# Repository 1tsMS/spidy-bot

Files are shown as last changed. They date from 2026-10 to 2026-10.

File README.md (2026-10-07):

# Spidy Bot

A 3D-printed 12-servo quadruped (ESP32 + PCA9685 + MG90S), with a MuJoCo model, leg IK, a crawl gait in simulation, and a desktop control app.

**Status:** stands and does slow sit/stand with some help. The crawl and turning work in simulation only. The real robot doesn't walk: the front legs don't have enough servo torque (details below).

## Hardware

| Part | Used |
|---|---|
| Frame | PLA, designed in Fusion 360, 4 legs × 3 joints (hip, knee, claw) |
| Servos | 12× MG90S |
| Servo driver | PCA9685 @ 0x40, 50 Hz, with a custom breakout board on top |
| Controller | ESP32 (uPesy Wroom DevKit), Wi-Fi |
| IMU | MPU6050 |
| Battery | 3S 11.1 V 2200 mAh LiPo |
| Servo supply | 12 A 300 W buck, set to 6 V |
| ESP supply | Mini360 buck, 5 V, fed from the battery side |

Leg lengths: coxa 34.2 mm, femur 55.8 mm, tibia 88.9 mm. Total mass 704 g.

## Software

| Path | What |
|---|---|
| `Codess/Software/` | **Old version.** ESP32 firmware with calibration hardcoded on the board, plus a PyQt5 tool for per-servo calibration and poses. |
| `Codess/Software2.0/` | **New version.** PySide6 app: live MuJoCo view, joystick driving, calibration wizard, pose library, 50 Hz Wi-Fi streaming to the robot. Run `Spidy.bat` or `python run_app.py`. |
| `firmware/spidy_fw/` | Firmware for the new app. All calibration lives on the PC; the ESP only drives pulses, holds the last pose if Wi-Fi drops, and reports its reset reason and I2C health. |
| `Codess/Simulation/sim_walk/` | Walking in MuJoCo step by step: IK, standing, body shift, crawl, turning. |
| `URDF/spidy_description/` | URDF and MuJoCo model generated from the Fusion CAD. |

Wi-Fi credentials go in `secrets.h` (copy `secrets.example.h`); it's gitignored.

## Problems and what fixed them

1. **Servo horns at the wrong angle.** Each servo was centred to 90° in software *before* its horn was screwed on, so all legs started from a known position.
2. **"90°" didn't look like 90° on the real legs.** Horn splines and print tolerances left every joint a few degrees off. Added a per-servo offset and direction, saved to a calibration file.
3. **Couldn't sit and stand.** A direct move overloaded the knees. I found a working standing pose (`Standf`, knees bent, tibias vertical) and an ordered chain of intermediate poses by hand. The new app adds IK-planned sit/stand sequences and a step reducer (aggressive / balanced / conservative).
4. **Power.** The original 18650 cells + XL4015 buck sagged under servo load. Replaced them with a 3S 2200 mAh LiPo and a 12 A buck.
5. **Thin PCA9685 power traces.** The board's own traces can't carry 12 servos' current. Made a breakout board that sits on the PCA9685 like a hat, with header pins and thick solder traces for servo power.
6. **ESP32 rebooting during moves.** Brownouts from servo current spikes. Confirmed by having the firmware report the ESP32's reset reason (`boot=BROWNOUT`). Fixed by:
   - moving the Mini360 input from the 6 V servo rail to the battery side,
   - adding 1000 µF + 100 nF at the ESP,
   - adding 1000 µF on the servo rail at the breakout.
7. **Servo scale was wrong.** The old firmware's "degrees" were ~1.46 real degrees (pulse range 100–700 ticks vs the MG90S's 0.5–2.5 ms). Found it because the real Sit pose only matched the sim at that scale. Corrected in the calibration, with pulses unchanged.

## Open problem: weak front legs

This has been there since day one, and the power and wiring fixes didn't change it.

- **Cause:** the battery and buck sit at the front, so the centre of mass is ~12 mm forward.
- In simulation the front knees need **~43% of a genuine MG90S's stall torque just to stand**, against ~29% for the rear knees.
- Servos can only hold roughly 25–50% of stall continuously, and most MG90S sold are clones with well under the rated 2.2 kg·cm. So the front knees run at or past their limit, and transitions need help.
- Swapping the front servos didn't fix it.
- **Likely fixes:** move the battery ~30 mm back (balances front and rear in sim), and use stronger knee servos (≈3.5 kg·cm, e.g. MG92B).

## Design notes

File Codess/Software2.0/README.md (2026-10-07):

# Spidy Control app

Desktop app to calibrate, pose and walk Spidy, in the MuJoCo sim and on the real robot.

```
pip install -r requirements.txt
python -m app                 # from Codess/Software2.0
python -m unittest discover -s tests -v      # from Codess/Software2.0
```

## Layout

| Path | What |
|---|---|
| `spidy/` | Core, no GUI: kinematics, gait, calibration, link, sim, IMU, poses |
| `app/` | PySide6 GUI: Dashboard, Motors, Calibration wizard, Poses |
| `config/calibration.json` | The ONLY calibration. Imported once from `../Software/spidy_calibration3.txt` |
| `config/poses.json` | Poses in joint degrees + sequences. Imported once from `spidy_poses.txt` |
| `firmware/spidy_fw/` | New firmware: pulses in, servos out. Needs `secrets.h` (copy `secrets.example.h`) |

## Calibration model

```
ticks = center + direction * ticks_per_deg * joint_deg      (clamped to min/max joint degrees)
```

`joint_deg` is the same angle the sim and IK use (0 = femur flat, tibia vertical).

## Safety

- Nothing reaches the real servos unless the target is REAL/BOTH **and** ARM is on.
- Arming first reads the servos' current pulses (`STATE`) so streaming starts there, without a jump.
- Every target goes through a 240°/s slew limit and each joint's min/max.
- E-STOP (button or Space) turns every output off and disarms.
- If the stream stops for 300 ms, the firmware holds the last pose.

## Keys

W/S forward/back, A/D turn (combine for arcs), Space = E-STOP. Gamepad: left stick, A stand, B sit, Back = E-STOP.

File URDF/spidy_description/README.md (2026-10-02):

# spidy_description

URDF + MuJoCo model of Spidy, generated from the Fusion model `MS makda urdf 2`.

## Layout

| Path | What | Edit by hand? |
|---|---|---|
| `urdf/spidy.urdf.xacro` | Robot structure: links, joints, leg macro | **Yes**, this is the URDF to read and learn from |
| `urdf/spidy_generated.xacro` | Numbers: lengths, masses, inertias | No, it's written by `build_description.py` |
| `urdf/spidy.urdf` | Plain expanded URDF (meshes `../meshes`) | No, regenerate with xacro |
| `config/masses.yaml` | Mass budget (**estimates**, weigh and replace) | Yes |
| `config/fusion_transforms.json` | Component placements exported from Fusion | No |
| `meshes/*.stl` | One mesh per link, in that link's frame, metres | No |
| `mujoco/spidy.xml` | MuJoCo model: free base, floor, 12 position servos, IMU | No, it's written by `urdf_to_mujoco.py` |

## Use

```bash
pip install -r requirements.txt
python -m mujoco.viewer --mjcf=mujoco/spidy.xml      # open it, drag the ctrl sliders
python scripts/check_model.py                        # joint-axis images + stand torque audit
```

After weighing parts (edit `config/masses.yaml`):

```bash
python scripts/build_description.py --raw ../raw_world_stl   # meshes + spidy_generated.xacro
xacro urdf/spidy.urdf.xacro mesh_prefix:=../meshes > urdf/spidy.urdf
python scripts/urdf_to_mujoco.py
```

## Conventions

- Frame: x forward, y left, z up. Base origin is the body centre at knee-axis height.
- Zero pose: the pose in the Fusion model (femur horizontal, tibia vertical).
- Every leg uses the same axes: hip +z, knee +x, claw +x. So `+knee` lifts a left leg and lowers a right leg. The gait code handles the mirroring.
- Joint limits are ±90° placeholders until they're mapped from the servo calibration.

## Leg geometry (from Fusion)

| | mm |
|---|---|
| hip axes from body centre | x ±60, y ±50 |
| coxa (hip → knee) | 34.2 |
| femur (knee → claw) | 55.8 |
| tibia (claw → foot tip) | 88.9 down; tip sits 5.0 toward body centre (x) and 1.2 inward (y) |

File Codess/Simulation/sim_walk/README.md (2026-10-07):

# sim_walk: making Spidy walk in MuJoCo, one idea per file

Each step builds on the one before and runs on its own. Run them from `Codess/Simulation`.

| File | Idea | Run |
|---|---|---|
| `step1_leg_ik.py` | FK + IK for one leg, tested against MuJoCo. Converts your logical servo degrees (Standf) to joint angles | `python sim_walk/step1_leg_ik.py` |
| `step2_stand.py` | Stand in Standf, feet planted, move the body (height, sway, twist) | `python sim_walk/step2_stand.py` |
| `step3_body_shift.py` | Shift the COM over 3 feet before lifting the 4th | `python sim_walk/step3_body_shift.py` (try `--no-shift`) |
| `step4_crawl.py` | Wave gait: body moves continuously, one leg swings at a time, body sways | `python sim_walk/step4_crawl.py` |
| `step5_turn.py` | Turning: stance feet sweep arcs instead of straight lines | `python sim_walk/step5_turn.py` |

Add `--headless` to any of them to skip the viewer and print a test report instead.

`simrun.py` is shared plumbing (load the model, real-time loop, measurements). No walking ideas live here.

## Assumptions to check on the real bot

- `STANDF = [90, 105, 75]` from `Codess/Software/spidy_poses.txt`, read as knee +15 / claw -15 from the modelled pose.
- +knee raises the femur on every leg (implied by the Sit pose). Hip direction is not verified.
- `DEG_PER_LOGICAL = 1.0`: one logical degree is assumed to be one real degree. Not measured.

## Results (704 g model, servo stall 0.21 N*m)

- Crawl: 2.9 cm/s, 14 mm stability margin, about 1 deg body tilt.
- Servo load while crawling straight: knee ~87%, claw ~74% of stall.
- Turning: arc +47 deg (asked ~50), spin -65 deg (asked ~62). Knees reach ~92% while spinning: the tightest case.

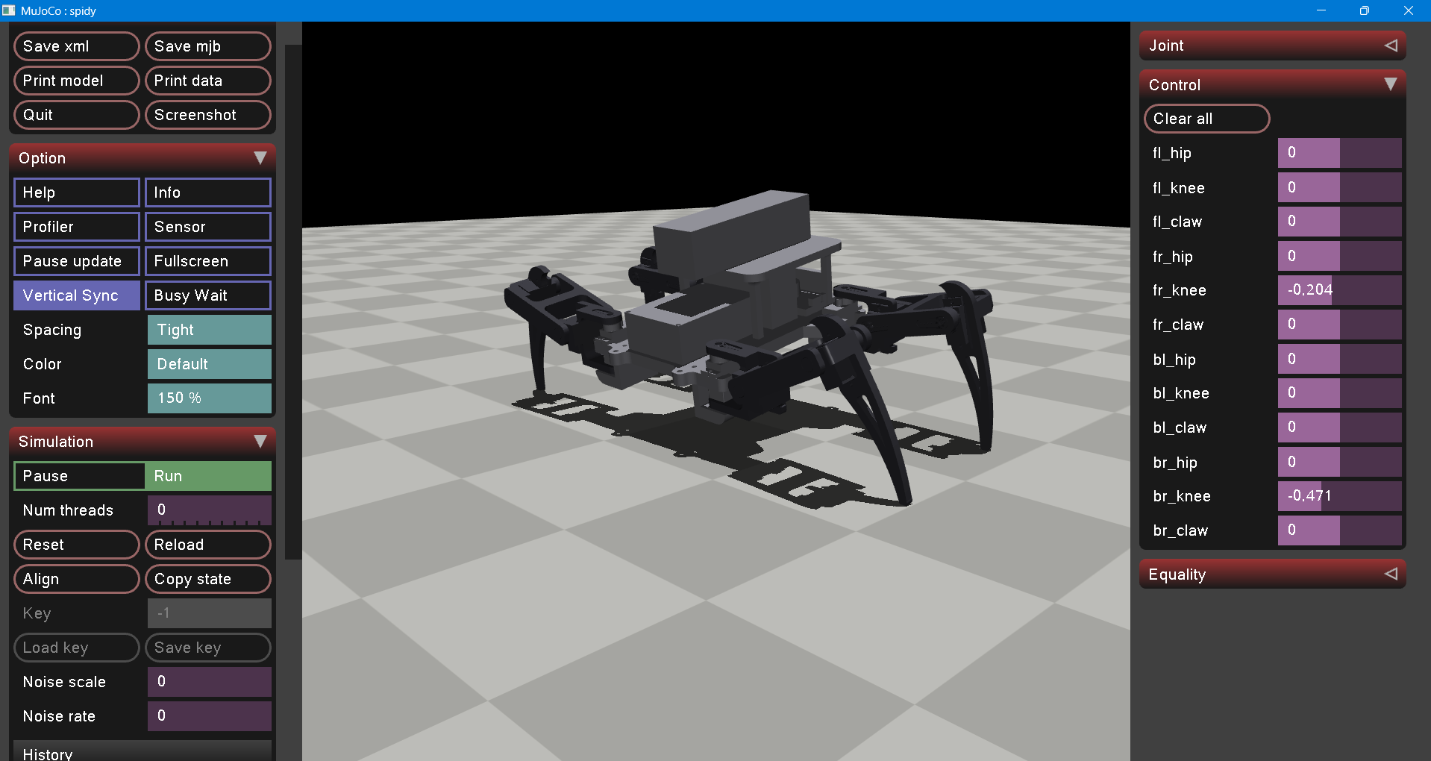
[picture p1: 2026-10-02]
images/Screenshot 2026-10-02 173417.png

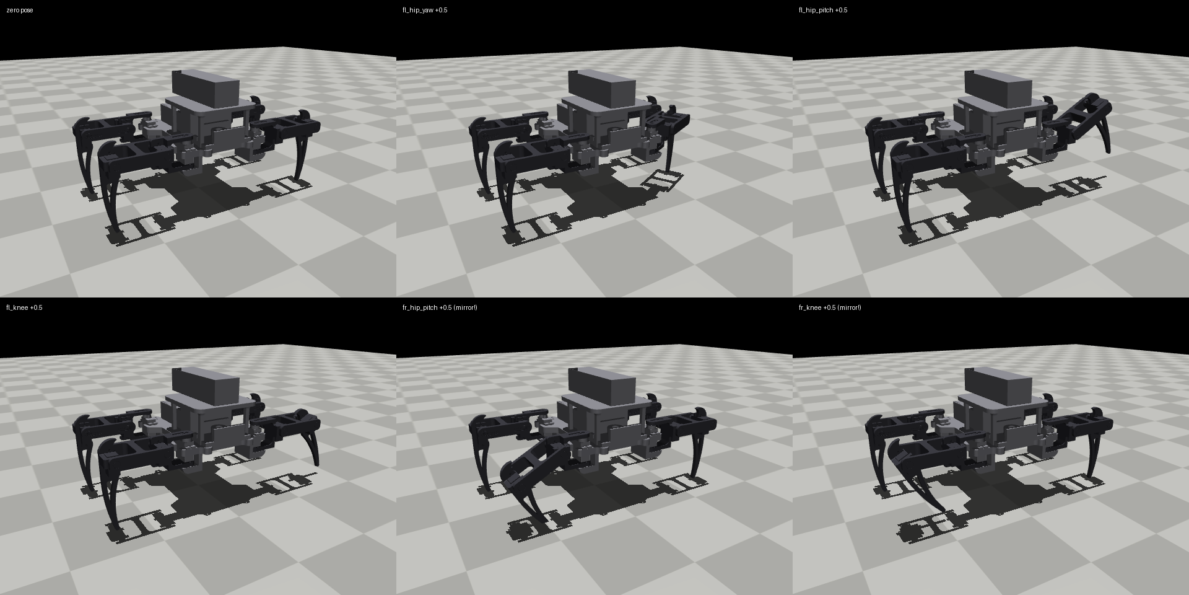
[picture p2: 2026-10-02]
images/joint_axes.png

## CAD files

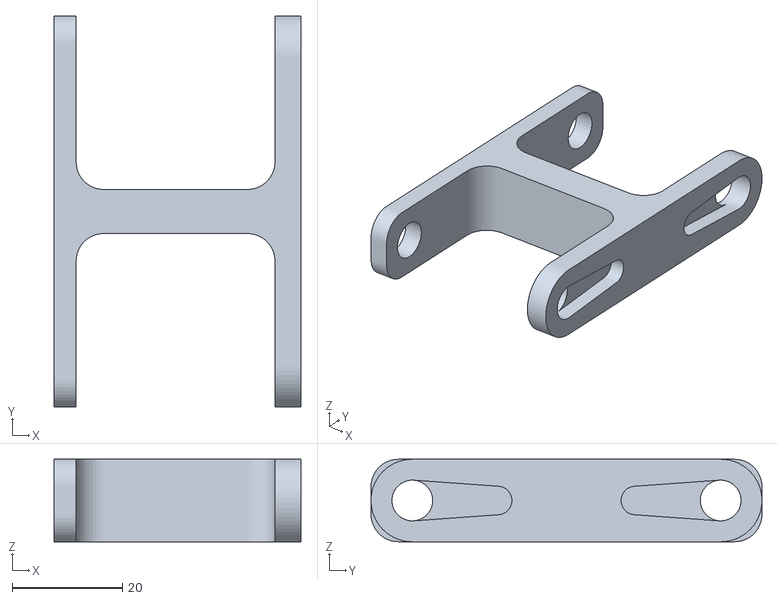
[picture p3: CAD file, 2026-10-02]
Final Parts/Link.stl
44.8 x 71.0 x 15.0

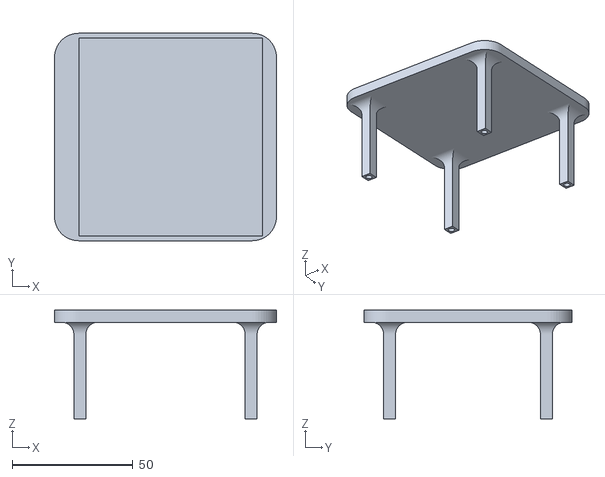
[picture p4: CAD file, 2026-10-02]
Models/Table.stl
92.0 x 86.0 x 45.0

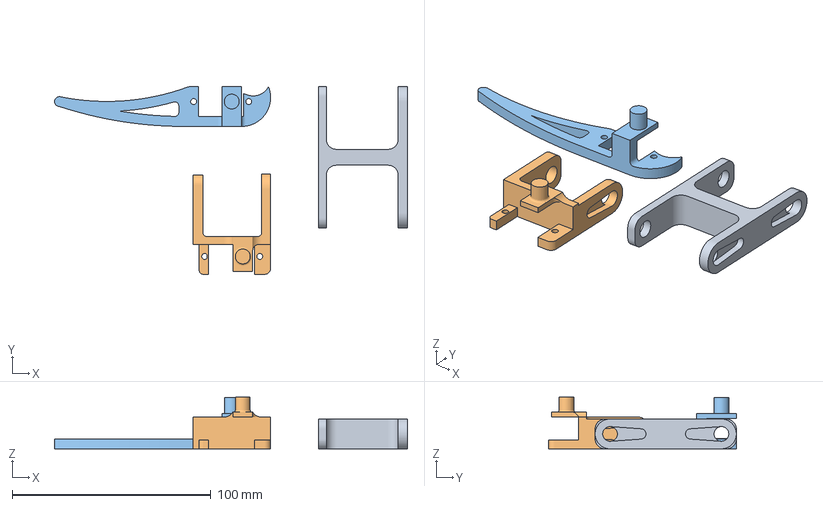
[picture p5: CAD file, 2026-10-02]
Prints/leg.3mf
177.4 x 94.4 x 26.0 mm
Part 2.stl
part1.stl
Body1.stl

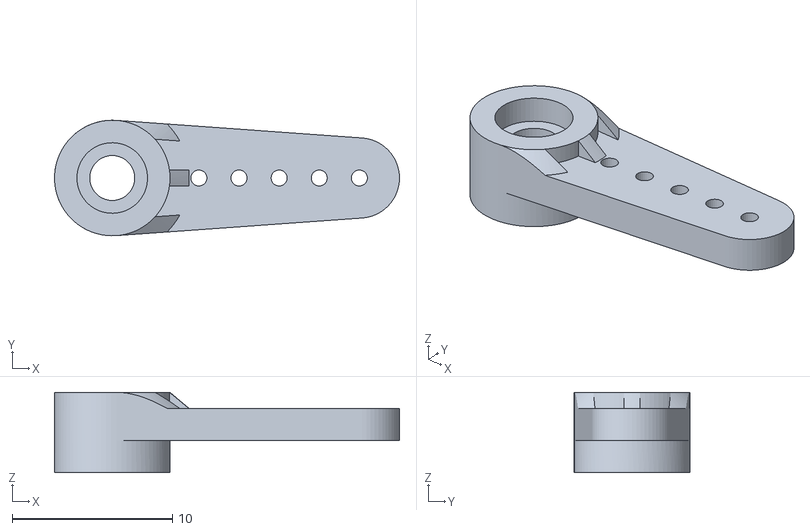
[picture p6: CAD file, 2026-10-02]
URDF/raw_world_stl/m2_horn_fl.stl
21.5 x 7.20 x 5.00

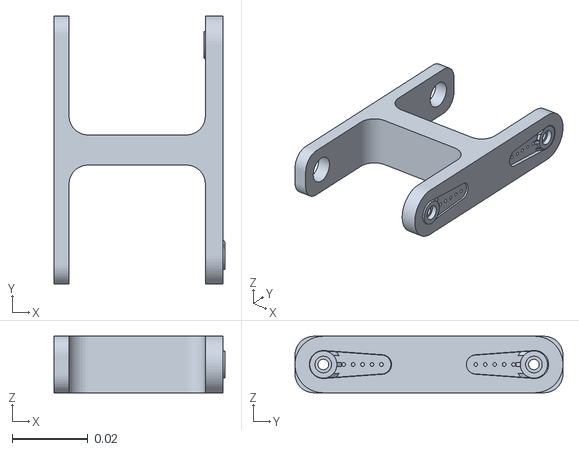
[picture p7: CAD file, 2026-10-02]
URDF/spidy_description/meshes/br_femur.stl
0.0453 x 0.071 x 0.015

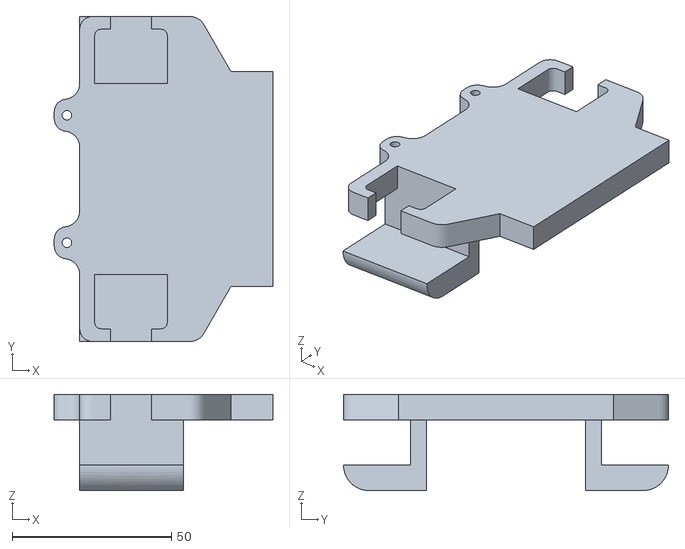
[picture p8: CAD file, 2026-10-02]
Final Parts/body test.stl
68.6 x 102.0 x 30.2

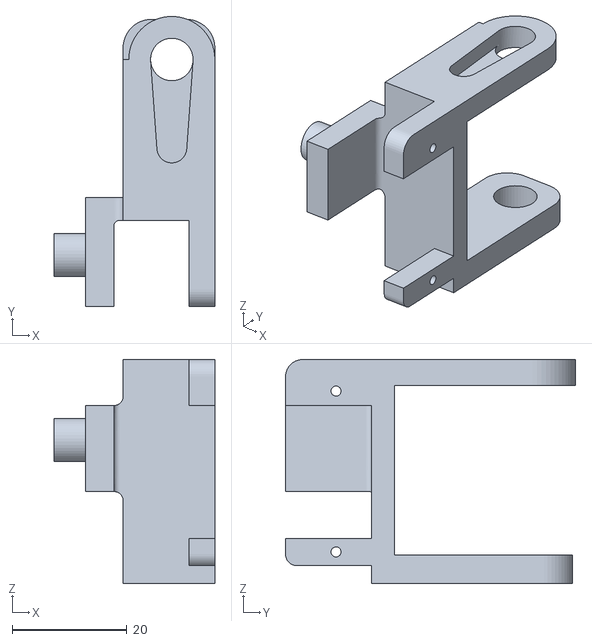
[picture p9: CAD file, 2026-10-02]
Models/Body3.stl
28.0 x 50.5 x 39.0

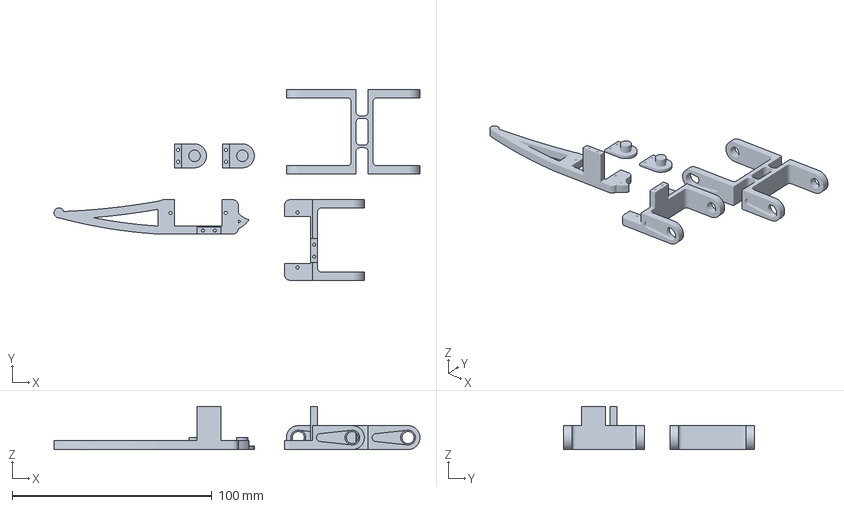
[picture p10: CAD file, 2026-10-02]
Prints/leg r.3mf
183.4 x 95.6 x 21.6 mm

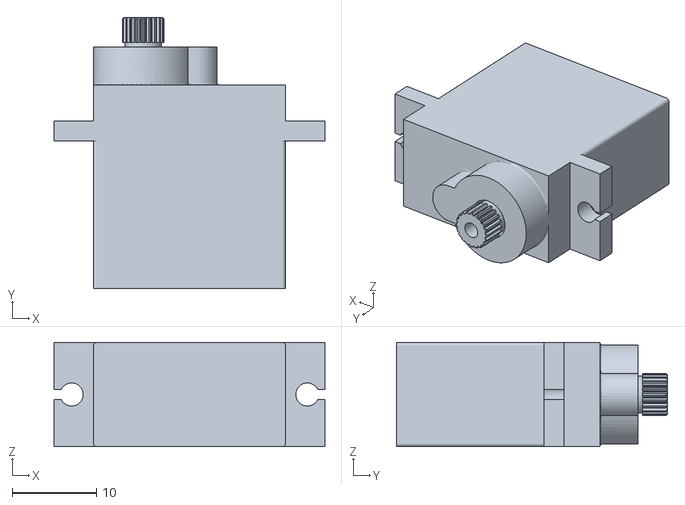
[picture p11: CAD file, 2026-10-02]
URDF/raw_world_stl/m1_fl.stl
32.2 x 32.2 x 12.4

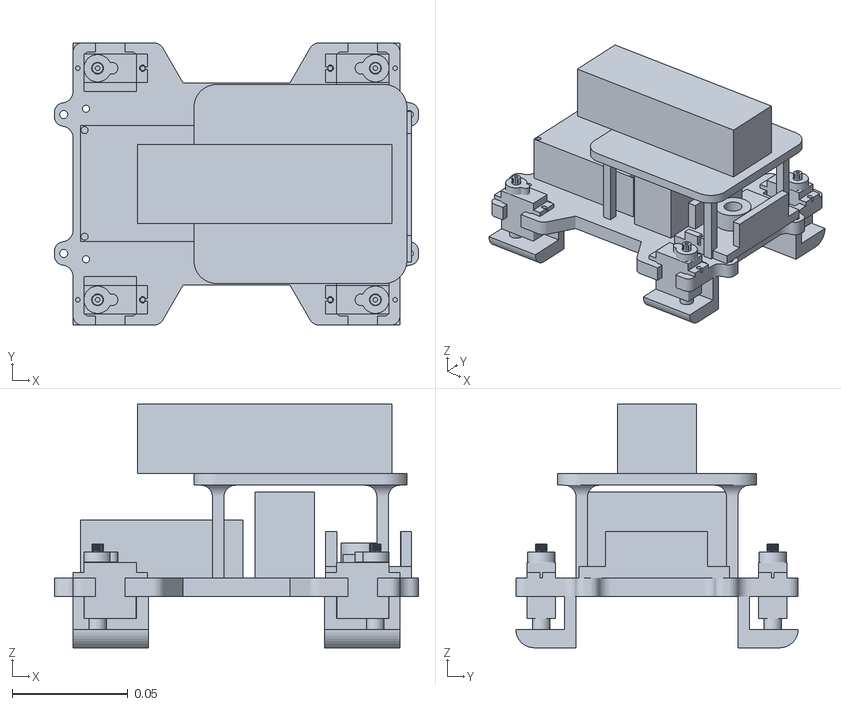
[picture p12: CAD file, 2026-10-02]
URDF/spidy_description/meshes/base_link.stl
0.157 x 0.122 x 0.105

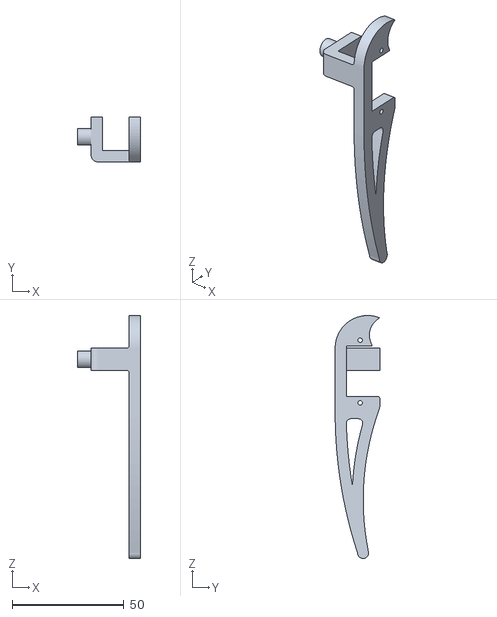
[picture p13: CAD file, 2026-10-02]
Final Parts/Leg1_claw.stl
28.0 x 20.0 x 108.6

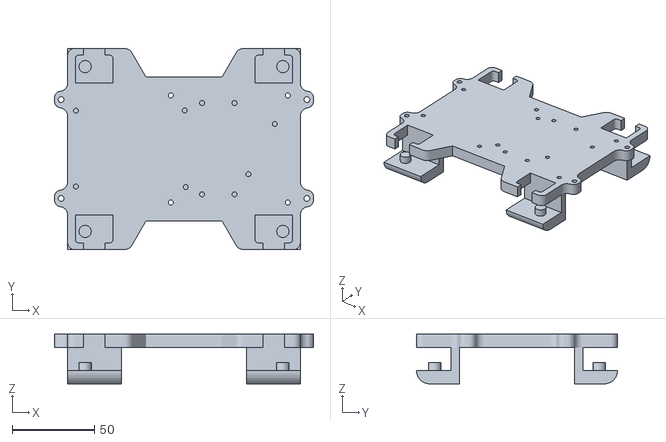
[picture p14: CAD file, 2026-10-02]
Models/Chassis.stl
157.2 x 122.0 x 30.2

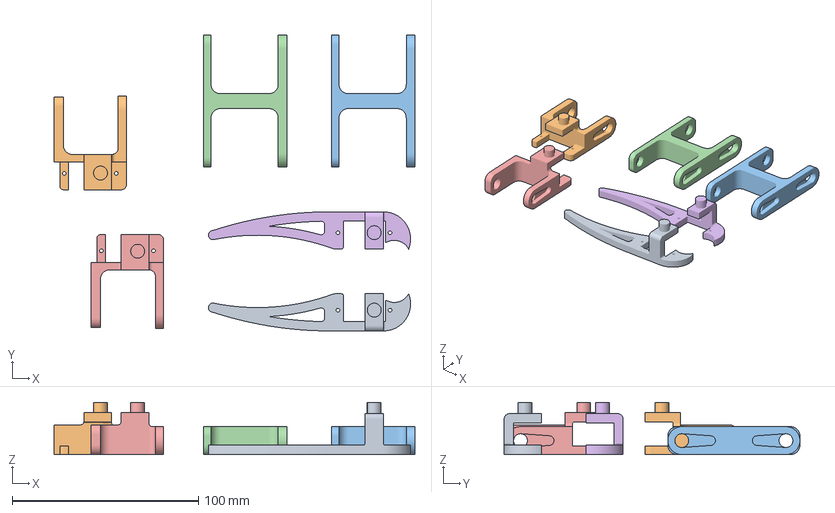
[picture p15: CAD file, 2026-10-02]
Prints/2legs.3mf
194.0 x 159.0 x 28.0 mm
Leg1_claw.stl
Leg1_Shldr.stl
Link.stl x 2
Leg2_Shldr.stl
Leg2_Claw.stl

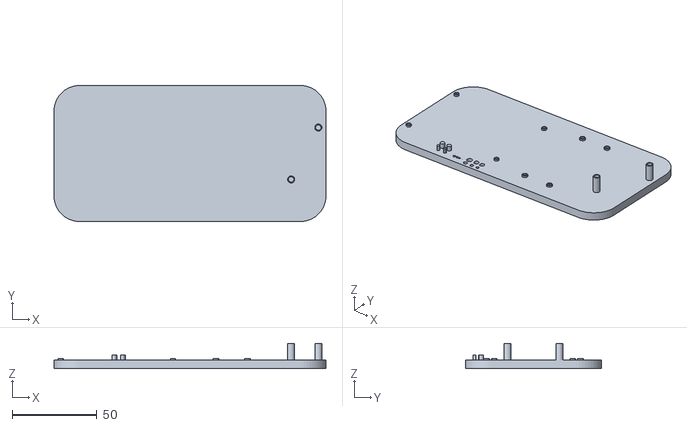
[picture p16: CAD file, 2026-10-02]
Models/Holes Test.stl
160.0 x 80.0 x 15.0

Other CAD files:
URDF/raw_world_stl/m1_bl.stl
URDF/spidy_description/meshes/fl_femur.stl
Final Parts/Leg2_Claw.stl
URDF/raw_world_stl/m3_horn_fr.stl
Final Parts/Leg1_Shldr.stl
Final Parts/Leg2_Shldr.stl
Models/Body1.stl
Models/Part 2.stl
Models/part1.stl
URDF/raw_world_stl/BUCK.stl
URDF/raw_world_stl/Battery.stl
URDF/raw_world_stl/MCU_board.stl
URDF/raw_world_stl/PCA.stl
URDF/raw_world_stl/TABLE.stl
URDF/raw_world_stl/base_link.stl
URDF/raw_world_stl/claw_bl.stl
URDF/raw_world_stl/claw_br.stl
URDF/raw_world_stl/claw_fl.stl
URDF/raw_world_stl/claw_fr.stl
URDF/raw_world_stl/elbow_bl.stl
URDF/raw_world_stl/elbow_br.stl
URDF/raw_world_stl/elbow_fl.stl
URDF/raw_world_stl/elbow_fr.stl
URDF/raw_world_stl/m1_fr.stl
URDF/raw_world_stl/m1_horn_bl.stl
URDF/raw_world_stl/m1_horn_fr.stl
URDF/raw_world_stl/m2_bl.stl
URDF/raw_world_stl/m2_fr.stl
URDF/raw_world_stl/m2_horn_bl.stl
URDF/raw_world_stl/m2_horn_fr.stl
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

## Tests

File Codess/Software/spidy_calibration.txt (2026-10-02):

Motor	Index	Joint	Dir	Offset	Signal	Min	Max
00	0	BL_HIP	-	+2	387	11	131
01	1	BL_KNEE	+	+0	400	14	157
02	2	BL_ANKLE	-	+0	400	44	138
03	15	BR_HIP	+	+4	413	9	129
04	14	BR_KNEE	-	-2	406	19	178
05	13	FL_HIP	+	+5	416	44	153
06	11	FR_HIP	+	+9	403	52	135
07	10	FR_KNEE	+	+0	400	15	154
08	9	FR_ANKLE	-	+0	400	47	180
09	3	FL_HIP	-	-6	420	55	173
10	4	FL_KNEE	-	+0	400	24	180
11	5	FL_ANKLE	+	-6	380	46	166
12	12	FL_HIP	+	+0	506	0	180
13	13	FL_HIP	+	+0	400	0	180
14	14	FL_HIP	+	+0	436	0	180
15	15	FL_HIP	+	+0	426	0	180

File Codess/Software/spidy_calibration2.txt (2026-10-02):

Motor	Index	Joint	Dir	Offset	Signal	Min	Max
00	0	BL_HIP	-	+4	387	27	127
01	1	BL_KNEE	+	+0	400	19	150
02	2	BL_ANKLE	-	+0	400	43	180
03	15	BR_HIP	+	+5	416	10	129
04	14	BR_KNEE	-	-3	410	33	180
05	13	BR_ANKLE	+	+6	420	43	145
06	11	FR_HIP	+	+0	400	53	133
07	10	FR_KNEE	+	+0	400	19	151
08	9	FR_ANKLE	-	+0	400	47	180
09	3	FL_HIP	-	-6	420	56	167
10	4	FL_KNEE	+	+0	400	0	180
11	5	FL_ANKLE	+	-4	387	40	159
12	6	AUX_1	+	+0	400	0	180
13	7	AUX_2	+	+0	400	0	180
14	8	AUX_3	+	+0	400	0	180
15	12	AUX_4	+	+0	400	0	180

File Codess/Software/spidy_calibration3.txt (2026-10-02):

Motor	Index	Joint	Dir	Offset	Signal	Min	Max
00	0	BL_HIP	-	+3	390	28	129
01	1	BL_KNEE	+	-3	390	22	153
02	2	BL_ANKLE	-	-2	407	41	180
03	3	FL_HIP	-	-6	420	57	174
04	4	FL_KNEE	-	+0	400	24	180
05	5	FL_ANKLE	+	-4	387	44	158
06	11	FR_HIP	+	+1	403	51	149
07	10	FR_KNEE	+	+0	400	17	158
08	9	FR_ANKLE	-	-1	403	49	180
09	15	BR_HIP	+	+4	413	4	131
10	14	BR_KNEE	-	+0	400	26	180
11	13	BR_ANKLE	+	+6	420	44	150
12	6	AUX_1	+	+0	400	0	180
13	7	AUX_2	+	+0	400	0	180
14	8	AUX_3	+	+0	400	0	180
15	12	AUX_4	+	+0	400	0	180

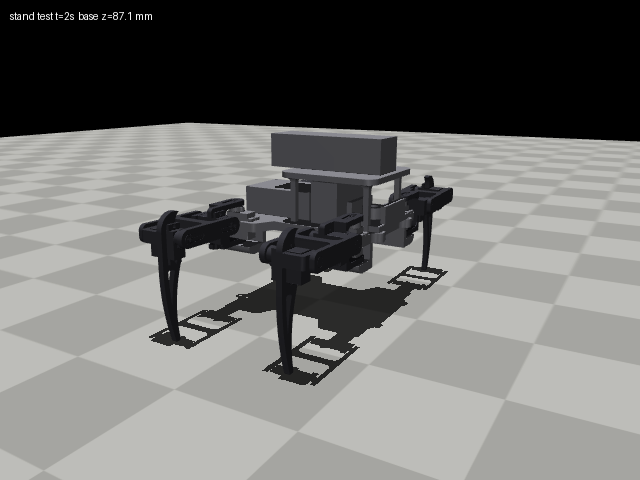
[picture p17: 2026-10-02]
URDF/spidy_description/mujoco/checks/stand_test.png

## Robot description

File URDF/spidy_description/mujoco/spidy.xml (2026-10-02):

<mujoco model="spidy">
  <compiler angle="radian" meshdir="../meshes/"/>

  <option integrator="implicitfast"/>

  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

  <worldbody>
    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
    <light pos="0 0 1.5" type="directional"/>
    <body name="base_link" pos="0 0 0.0909">
      <inertial pos="0.0121647 -0.000138725 0.0231342" quat="0.544247 0.456182 0.45671 0.535825" mass="0.517075" diaginertia="0.00130565 0.00108044 0.000819073"/>
      <joint name="root" type="free"/>
      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
      <body name="fl_coxa" pos="0.06 0.05 0">
        <inertial pos="-0.00178525 0.0295615 -0.00439371" quat="0.850268 0.512865 0.0168767 0.117174" mass="0.0200143" diaginertia="4.09863e-06 3.49091e-06 2.91166e-06"/>
        <joint name="fl_hip" range="-1.5708 1.5708" actuatorfrcrange="-0.21 0.21" armature="0.0002" damping="0.01" frictionloss="0.005"/>
        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
        <body name="fl_femur" pos="0 0.0342 0">
          <inertial pos="-0.00630845 0.0278224 5.95122e-10" quat="0.051045 0.705262 -0.0510469 0.705262" mass="0.00891947" diaginertia="5.38e-06 2.88631e-06 2.78449e-06"/>
          <joint name="fl_knee" range="-1.5708 1.5708" actuatorfrcrange="-0.21 0.21" armature="0.0002" damping="0.01" frictionloss="0.005" axis="1 0 0"/>
          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
          <body name="fl_tibia" pos="0 0.0558 0">
            <inertial pos="-0.00325911 0.00066042 -0.00898153" quat="0.698815 0.0214111 0.00379377 0.714972" mass="0.0179021" diaginertia="5.8423e-06 5.08082e-06 1.36038e-06"/>
            <joint name="fl_claw" range="-1.5708 1.5708" actuatorfrcrange="-0.21 0.21" armature="0.0002" damping="0.01" frictionloss="0.005" axis="1 0 0"/>
            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
            <body name="fl_foot" pos="-0.005 -0.00121 -0.0889"/>
          </body>
        </body>
      </body>
      <body name="fr_coxa" pos="0.06 -0.05 0">
        <inertial pos="-0.00178525 -0.0295615 -0.00439371" quat="0.512865 0.850268 -0.117174 -0.0168767" mass="0.0200143" diaginertia="4.09863e-06 3.49091e-06 2.91166e-06"/>
        <joint name="fr_hip" range="-1.5708 1.5708" actuatorfrcrange="-0.21 0.21" armature="0.0002" damping="0.01" frictionloss="0.005"/>
        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
        <body name="fr_femur" pos="0 -0.0342 0">
          <inertial pos="-0.00630845 -0.0278224 5.95122e-10" quat="-0.051045 0.705262 0.0510469 0.705262" mass="0.00891947" diaginertia="5.38e-06 2.88631e-06 2.78449e-06"/>
          <joint name="fr_knee" range="-1.5708 1.5708" actuatorfrcrange="-0.21 0.21" armature="0.0002" damping="0.01" frictionloss="0.005" axis="1 0 0"/>
          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
          <body name="fr_tibia" pos="0 -0.0558 0">
            <inertial pos="-0.00325911 -0.00066042 -0.00898153" quat="0.714972 0.00379377 0.0214111 0.698815" mass="0.0179021" diaginertia="5.8423e-06 5.08082e-06 1.36038e-06"/>
            <joint name="fr_claw" range="-1.5708 1.5708" actuatorfrcrange="-0.21 0.21" armature="0.0002" damping="0.01" frictionloss="0.005" axis="1 0 0"/>
            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
            <body name="fr_foot" pos="-0.005 0.00121 -0.0889"/>
          </body>
        </body>
      </body>
      <body name="bl_coxa" pos="-0.06 0.05 0">
        <inertial pos="0.00178525 0.0295615 -0.00439371" quat="0.850268 0.512865 -0.0168767 -0.117174" mass="0.0200143" diaginertia="4.09863e-06 3.49091e-06 2.91166e-06"/>
        <joint name="bl_hip" range="-1.5708 1.5708" actuatorfrcrange="-0.21 0.21" armature="0.0002" damping="0.01" frictionloss="0.005"/>
        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
        <body name="bl_femur" pos="0 0.0342 0">
          <inertial pos="0.00630845 0.0278224 5.95122e-10" quat="-0.0510469 0.705262 0.051045 0.705262" mass="0.00891947" diaginertia="5.38e-06 2.88631e-06 2.78449e-06"/>
          <joint name="bl_knee" range="-1.5708 1.5708" actuatorfrcrange="-0.21 0.21" armature="0.0002" damping="0.01" frictionloss="0.005" axis="1 0 0"/>
          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
          <body name="bl_tibia" pos="0 0.0558 0">
            <inertial pos="0.00325911 0.00066042 -0.00898153" quat="0.714972 -0.00379377 -0.0214111 0.698815" mass="0.0179021" diaginertia="5.8423e-06 5.08082e-06 1.36038e-06"/>
            <joint name="bl_claw" range="-1.5708 1.5708" actuatorfrcrange="-0.21 0.21" armature="0.0002" damping="0.01" frictionloss="0.005" axis="1 0 0"/>
            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
            <body name="bl_foot" pos="0.005 -0.00121 -0.0889"/>
          </body>
        </body>
      </body>
      <body name="br_coxa" pos="-0.06 -0.05 0">
        <inertial pos="0.00178525 -0.0295615 -0.00439371" quat="0.512865 0.850268 0.117174 0.0168767" mass="0.0200143" diaginertia="4.09863e-06 3.49091e-06 2.91166e-06"/>
        <joint name="br_hip" range="-1.5708 1.5708" actuatorfrcrange="-0.21 0.21" armature="0.0002" damping="0.01" frictionloss="0.005"/>
        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
        <body name="br_femur" pos="0 -0.0342 0">
          <inertial pos="0.00630845 -0.0278224 5.95122e-10" quat="0.0510469 0.705262 -0.051045 0.705262" mass="0.00891947" diaginertia="5.38e-06 2.88631e-06 2.78449e-06"/>
          <joint name="br_knee" range="-1.5708 1.5708" actuatorfrcrange="-0.21 0.21" armature="0.0002" damping="0.01" frictionloss="0.005" axis="1 0 0"/>
          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
          <body name="br_tibia" pos="0 -0.0558 0">
            <inertial pos="0.00325911 -0.00066042 -0.00898153" quat="0.698815 -0.0214111 -0.00379377 0.714972" mass="0.0179021" diaginertia="5.8423e-06 5.08082e-06 1.36038e-06"/>
            <joint name="br_claw" range="-1.5708 1.5708" actuatorfrcrange="-0.21 0.21" armature="0.0002" damping="0.01" frictionloss="0.005" axis="1 0 0"/>
            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
            <body name="br_foot" pos="0.005 0.00121 -0.0889"/>
          </body>
        </body>
      </body>
    </body>
  </worldbody>

  <actuator>
    <general name="fl_hip" joint="fl_hip" ctrlrange="-1.5708 1.5708" ctrllimited="true" forcelimited="true" forcerange="-0.21 0.21" biastype="affine" gainprm="4" biasprm="0 -4 -0.03"/>
    <general name="fl_knee" joint="fl_knee" ctrlrange="-1.5708 1.5708" ctrllimited="true" forcelimited="true" forcerange="-0.21 0.21" biastype="affine" gainprm="4" biasprm="0 -4 -0.03"/>
    <general name="fl_claw" joint="fl_claw" ctrlrange="-1.5708 1.5708" ctrllimited="true" forcelimited="true" forcerange="-0.21 0.21" biastype="affine" gainprm="4" biasprm="0 -4 -0.03"/>
    <general name="fr_hip" joint="fr_hip" ctrlrange="-1.5708 1.5708" ctrllimited="true" forcelimited="true" forcerange="-0.21 0.21" biastype="affine" gainprm="4" biasprm="0 -4 -0.03"/>
    <general name="fr_knee" joint="fr_knee" ctrlrange="-1.5708 1.5708" ctrllimited="true" forcelimited="true" forcerange="-0.21 0.21" biastype="affine" gainprm="4" biasprm="0 -4 -0.03"/>
    <general name="fr_claw" joint="fr_claw" ctrlrange="-1.5708 1.5708" ctrllimited="true" forcelimited="true" forcerange="-0.21 0.21" biastype="affine" gainprm="4" biasprm="0 -4 -0.03"/>
    <general name="bl_hip" joint="bl_hip" ctrlrange="-1.5708 1.5708" ctrllimited="true" forcelimited="true" forcerange="-0.21 0.21" biastype="affine" gainprm="4" biasprm="0 -4 -0.03"/>
    <general name="bl_knee" joint="bl_knee" ctrlrange="-1.5708 1.5708" ctrllimited="true" forcelimited="true" forcerange="-0.21 0.21" biastype="affine" gainprm="4" biasprm="0 -4 -0.03"/>
    <general name="bl_claw" joint="bl_claw" ctrlrange="-1.5708 1.5708" ctrllimited="true" forcelimited="true" forcerange="-0.21 0.21" biastype="affine" gainprm="4" biasprm="0 -4 -0.03"/>
    <general name="br_hip" joint="br_hip" ctrlrange="-1.5708 1.5708" ctrllimited="true" forcelimited="true" forcerange="-0.21 0.21" biastype="affine" gainprm="4" biasprm="0 -4 -0.03"/>
    <general name="br_knee" joint="br_knee" ctrlrange="-1.5708 1.5708" ctrllimited="true" forcelimited="true" forcerange="-0.21 0.21" biastype="affine" gainprm="4" biasprm="0 -4 -0.03"/>
    <general name="br_claw" joint="br_claw" ctrlrange="-1.5708 1.5708" ctrllimited="true" forcelimited="true" forcerange="-0.21 0.21" biastype="affine" gainprm="4" biasprm="0 -4 -0.03"/>
  </actuator>

  <sensor>
    <framequat objtype="site" objname="imu" name="imu_quat"/>
    <gyro site="imu" name="imu_gyro"/>
    <accelerometer site="imu" name="imu_acc"/>
  </sensor>
</mujoco>

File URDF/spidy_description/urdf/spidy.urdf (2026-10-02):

<?xml version="1.0" ?>
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
<robot name="spidy">
  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
  <link name="base_link">
    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
    <inertial>
      <origin rpy="0 0 0" xyz="0.0121647 -0.000138725 0.0231342"/>
      <mass value="0.517075"/>
      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
    </inertial>
  </link>
  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
  <joint name="fl_hip" type="revolute">
    <parent link="base_link"/>
    <child link="fl_coxa"/>
    <origin rpy="0 0 0" xyz="0.06 0.05 0"/>
    <axis xyz="0 0 1"/>
    <limit effort="0.21" lower="-1.5707963267948966" upper="1.5707963267948966" velocity="13.0"/>
  </joint>
  <link name="fl_coxa">
    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
    <inertial>
      <origin rpy="0 0 0" xyz="-0.00178525 0.0295615 -0.00439371"/>
      <mass value="0.0200143"/>
      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
    </inertial>
  </link>
  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
  <joint name="fl_knee" type="revolute">
    <parent link="fl_coxa"/>
    <child link="fl_femur"/>
    <origin rpy="0 0 0" xyz="0 0.0342 0"/>
    <axis xyz="1 0 0"/>
    <limit effort="0.21" lower="-1.5707963267948966" upper="1.5707963267948966" velocity="13.0"/>
  </joint>
  <link name="fl_femur">
    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
    <inertial>
      <origin rpy="0 0 0" xyz="-0.00630845 0.0278224 5.95122e-10"/>
      <mass value="0.00891947"/>
      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
    </inertial>
  </link>
  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
  <joint name="fl_claw" type="revolute">
    <parent link="fl_femur"/>
    <child link="fl_tibia"/>
    <origin rpy="0 0 0" xyz="0 0.0558 0"/>
    <axis xyz="1 0 0"/>
    <limit effort="0.21" lower="-1.5707963267948966" upper="1.5707963267948966" velocity="13.0"/>
  </joint>
  <link name="fl_tibia">
    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
    <inertial>
      <origin rpy="0 0 0" xyz="-0.00325911 0.00066042 -0.00898153"/>
      <mass value="0.0179021"/>
      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
    </inertial>
  </link>
  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
  <joint name="fl_foot_fixed" type="fixed">
    <parent link="fl_tibia"/>
    <child link="fl_foot"/>
    <origin rpy="0 0 0" xyz="-0.005 -0.00121 -0.0889"/>
  </joint>
  <link name="fl_foot"/>
  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
  <joint name="fr_hip" type="revolute">
    <parent link="base_link"/>
    <child link="fr_coxa"/>
    <origin rpy="0 0 0" xyz="0.06 -0.05 0"/>
    <axis xyz="0 0 1"/>
    <limit effort="0.21" lower="-1.5707963267948966" upper="1.5707963267948966" velocity="13.0"/>
  </joint>
  <link name="fr_coxa">
    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
    <inertial>
      <origin rpy="0 0 0" xyz="-0.00178525 -0.0295615 -0.00439371"/>
      <mass value="0.0200143"/>
      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
    </inertial>
  </link>
  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
  <joint name="fr_knee" type="revolute">
    <parent link="fr_coxa"/>
    <child link="fr_femur"/>
    <origin rpy="0 0 0" xyz="0 -0.0342 0"/>
    <axis xyz="1 0 0"/>
    <limit effort="0.21" lower="-1.5707963267948966" upper="1.5707963267948966" velocity="13.0"/>
  </joint>
  <link name="fr_femur">
    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
    <inertial>
      <origin rpy="0 0 0" xyz="-0.00630845 -0.0278224 5.95122e-10"/>
      <mass value="0.00891947"/>
      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
    </inertial>
  </link>
  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
  <joint name="fr_claw" type="revolute">
    <parent link="fr_femur"/>
    <child link="fr_tibia"/>
    <origin rpy="0 0 0" xyz="0 -0.0558 0"/>
    <axis xyz="1 0 0"/>
    <limit effort="0.21" lower="-1.5707963267948966" upper="1.5707963267948966" velocity="13.0"/>
  </joint>
  <link name="fr_tibia">
    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
    <inertial>
      <origin rpy="0 0 0" xyz="-0.00325911 -0.00066042 -0.00898153"/>
      <mass value="0.0179021"/>
      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
    </inertial>
  </link>
  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
  <joint name="fr_foot_fixed" type="fixed">
    <parent link="fr_tibia"/>
    <child link="fr_foot"/>
    <origin rpy="0 0 0" xyz="-0.005 0.00121 -0.0889"/>
  </joint>
  <link name="fr_foot"/>
  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
  <joint name="bl_hip" type="revolute">
    <parent link="base_link"/>
    <child link="bl_coxa"/>
    <origin rpy="0 0 0" xyz="-0.06 0.05 0"/>
    <axis xyz="0 0 1"/>
    <limit effort="0.21" lower="-1.5707963267948966" upper="1.5707963267948966" velocity="13.0"/>
  </joint>
  <link name="bl_coxa">
    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
    <inertial>
      <origin rpy="0 0 0" xyz="0.00178525 0.0295615 -0.00439371"/>
      <mass value="0.0200143"/>
      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
    </inertial>
  </link>
  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
  <joint name="bl_knee" type="revolute">
    <parent link="bl_coxa"/>
    <child link="bl_femur"/>
    <origin rpy="0 0 0" xyz="0 0.0342 0"/>
    <axis xyz="1 0 0"/>
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

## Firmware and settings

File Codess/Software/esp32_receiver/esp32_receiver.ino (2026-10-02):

#include <Wire.h>
#include <Adafruit_PWMServoDriver.h>
#include <WiFi.h>

// Serial protocol (lines):
//   M,<id>,<pulse>   -> move servo id (0-15) to raw PCA9685 tick pulse
//   IDX,<id>,<idx>   -> map logical id to physical channel
//   POSE,<a0>...<a11>[,<duration_ms>] -> smooth 12-joint logical-angle motion
//   DUR,<ms>         -> set default POSE motion duration
//   SPD,<percent>    -> set motion speed percentage (1-100)
//   ESTOP            -> disable all outputs (sets all channels off)
// Same line protocol is accepted via WiFi TCP on WIFI_PORT.

// WiFi credentials live in secrets.h (gitignored). Copy secrets.example.h -> secrets.h.
#include "secrets.h"
static const uint16_t WIFI_PORT = 5000;

WiFiServer tcpServer(WIFI_PORT);
WiFiClient tcpClient;

Adafruit_PWMServoDriver pwm = Adafruit_PWMServoDriver(0x40);

static const uint16_t SERVO_MIN = 100;
static const uint16_t SERVO_MAX = 700;
static const uint16_t SERVO_FREQ = 50;
static const uint8_t ANGLE_MIN = 0;
static const uint8_t ANGLE_MAX = 180;
static const uint8_t LOGICAL_JOINT_COUNT = 12;
static const uint16_t DEFAULT_MOTION_DURATION_MS = 800;
static const uint16_t MIN_MOTION_DURATION_MS = 50;
static const uint16_t MAX_MOTION_DURATION_MS = 10000;

static const uint8_t SERVO_COUNT = 16;
static uint16_t lastPulses[SERVO_COUNT];
static uint8_t motorMap[SERVO_COUNT];

static float currentAngle[LOGICAL_JOINT_COUNT];
static float startAngle[LOGICAL_JOINT_COUNT];
static float targetAngle[LOGICAL_JOINT_COUNT];
static bool isMoving = false;
static uint32_t motionStartMs = 0;
static uint16_t motionDurationMs = DEFAULT_MOTION_DURATION_MS;
static uint16_t defaultMotionDurationMs = DEFAULT_MOTION_DURATION_MS;
static uint8_t speedPercent = 100;

// Default startup profile from spidy_calibration3.txt + Sit pose from spidy_poses.txt
static const int8_t CALIB_DIR[SERVO_COUNT] = {
  -1, +1, -1, -1, -1, +1, +1, +1,
  -1, +1, -1, +1, +1, +1, +1, +1,
};

static const int8_t CALIB_OFFSET[SERVO_COUNT] = {
  +3, -3, -2, -6, +0, -4, +1, +0,
  -1, +4, +0, +6, +0, +0, +0, +0,
};

static const uint8_t CALIB_MIN[SERVO_COUNT] = {
  28, 22, 41, 57, 24, 44, 51, 17,
  49, 4, 26, 44, 0, 0, 0, 0,
};

static const uint8_t CALIB_MAX[SERVO_COUNT] = {
  129, 153, 180, 174, 180, 158, 149, 158,
  180, 131, 180, 150, 180, 180, 180, 180,
};

static const uint8_t CALIB_INDEX[SERVO_COUNT] = {
  0, 1, 2, 3, 4, 5, 11, 10,
  9, 15, 14, 13, 6, 7, 8, 12,
};

static const uint8_t STARTUP_SIT_ANGLES[SERVO_COUNT] = {
  90, 120, 100, 90, 120, 100, 90, 120,
  100, 90, 120, 100, 90, 90, 90, 90,
};

String lineBuffer;
String wifiLineBuffer;

void sendReply(const String &msg) {
  Serial.println(msg);
  if (tcpClient && tcpClient.connected()) {
    tcpClient.println(msg);
  }
}

void writeServo(uint8_t channel, uint16_t pulse) {
  if (channel >= SERVO_COUNT) return;
  pulse = constrain(pulse, SERVO_MIN, SERVO_MAX);
  lastPulses[channel] = pulse;
  pwm.setPWM(channel, 0, pulse);
}

void writeMappedServo(uint8_t logicalId, uint16_t pulse) {
  if (logicalId >= SERVO_COUNT) return;
  uint8_t channel = motorMap[logicalId];
  if (channel >= SERVO_COUNT) return;
  writeServo(channel, pulse);
}

uint8_t mappedChannel(uint8_t logicalId) {
  if (logicalId >= SERVO_COUNT) return 255;
  uint8_t channel = motorMap[logicalId];
  if (channel >= SERVO_COUNT) return 255;
  return channel;
}

void emergencyStop() {
  for (uint8_t i = 0; i < SERVO_COUNT; i++) {
    pwm.setPWM(i, 0, 0);
  }
}

uint16_t computePulseFromLogicalAngle(uint8_t logicalId, uint8_t logicalAngle) {
  if (logicalId >= SERVO_COUNT) return SERVO_MIN;

  int corrected = constrain((int)logicalAngle, (int)ANGLE_MIN, (int)ANGLE_MAX);
  if (CALIB_DIR[logicalId] < 0) {
    corrected = 180 - corrected;
  }

  int offset = (int)CALIB_OFFSET[logicalId];
  if (CALIB_DIR[logicalId] < 0) {
    offset = -offset;
  }
  corrected += offset;

  corrected = constrain(corrected, (int)CALIB_MIN[logicalId], (int)CALIB_MAX[logicalId]);
  int pulse = (int)SERVO_MIN + (corrected * ((int)SERVO_MAX - (int)SERVO_MIN) + 90) / 180;
  return (uint16_t)constrain(pulse, (int)SERVO_MIN, (int)SERVO_MAX);
}

void applyLogicalAngleToServo(uint8_t logicalId, float logicalAngle) {
  if (logicalId >= LOGICAL_JOINT_COUNT) return;
  int constrainedAngle = constrain((int)(logicalAngle + 0.5f), (int)ANGLE_MIN, (int)ANGLE_MAX);
  uint16_t pulse = computePulseFromLogicalAngle(logicalId, (uint8_t)constrainedAngle);
  writeMappedServo(logicalId, pulse);
}

void applyAllCurrentAngles() {
  for (uint8_t i = 0; i < LOGICAL_JOINT_COUNT; i++) {
    applyLogicalAngleToServo(i, currentAngle[i]);
  }
}

void startPoseMotion(const float newTarget[LOGICAL_JOINT_COUNT], uint16_t durationMs) {
  for (uint8_t i = 0; i < LOGICAL_JOINT_COUNT; i++) {
    startAngle[i] = currentAngle[i];
    targetAngle[i] = (float)constrain((int)(newTarget[i] + 0.5f), (int)ANGLE_MIN, (int)ANGLE_MAX);
  }

  motionDurationMs = constrain(durationMs, MIN_MOTION_DURATION_MS, MAX_MOTION_DURATION_MS);
  motionStartMs = millis();
  isMoving = true;
}

void updateMotion() {
  if (!isMoving) return;

  uint32_t now = millis();
  uint32_t elapsed = now - motionStartMs;
  float progress = (motionDurationMs > 0) ? ((float)elapsed / (float)motionDurationMs) : 1.0f;
  if (progress >= 1.0f) {
    progress = 1.0f;
  }
  if (progress < 0.0f) {
    progress = 0.0f;
  }

  float eased = progress * progress * (3.0f - 2.0f * progress);
  for (uint8_t i = 0; i < LOGICAL_JOINT_COUNT; i++) {
    currentAngle[i] = startAngle[i] + (targetAngle[i] - startAngle[i]) * eased;
  }

  applyAllCurrentAngles();

  if (progress >= 1.0f) {
    for (uint8_t i = 0; i < LOGICAL_JOINT_COUNT; i++) {
      currentAngle[i] = targetAngle[i];
    }
    isMoving = false;
  }
}

void applyStartupSitPose() {
  for (uint8_t logicalId = 0; logicalId < SERVO_COUNT; logicalId++) {
    motorMap[logicalId] = CALIB_INDEX[logicalId];
  }

  for (uint8_t logicalId = 0; logicalId < SERVO_COUNT; logicalId++) {
    uint16_t pulse = computePulseFromLogicalAngle(logicalId, STARTUP_SIT_ANGLES[logicalId]);
    writeMappedServo(logicalId, pulse);
  }

  for (uint8_t i = 0; i < LOGICAL_JOINT_COUNT; i++) {
    float a = (float)STARTUP_SIT_ANGLES[i];
    currentAngle[i] = a;
    startAngle[i] = a;
    targetAngle[i] = a;
  }
  isMoving = false;
}

bool parsePoseCommand(const String &line, float outAngles[LOGICAL_JOINT_COUNT], uint16_t &outDurationMs) {
  if (!line.startsWith("POSE,")) return false;

  uint8_t valueCount = 0;
  int start = 5;
  int len = line.length();
  outDurationMs = defaultMotionDurationMs;

  while (start <= len) {
    int comma = line.indexOf(',', start);
    if (comma < 0) comma = len;

    String token = line.substring(start, comma);
    token.trim();
    if (token.length() > 0) {
      if (valueCount < LOGICAL_JOINT_COUNT) {
        outAngles[valueCount] = token.toFloat();
      } else if (valueCount == LOGICAL_JOINT_COUNT) {
        int d = token.toInt();
        outDurationMs = (uint16_t)constrain(d, (int)MIN_MOTION_DURATION_MS, (int)MAX_MOTION_DURATION_MS);
      }
      valueCount++;
    }

    if (comma >= len) break;
    start = comma + 1;
  }

  return valueCount >= LOGICAL_JOINT_COUNT;
}

void setup() {
  Serial.begin(115200);
  Wire.begin();
  pwm.begin();
  pwm.setPWMFreq(SERVO_FREQ);
  uint16_t zeroPulse = (SERVO_MIN + SERVO_MAX) / 2;
  for (uint8_t i = 0; i < SERVO_COUNT; i++) {
    lastPulses[i] = zeroPulse;
    motorMap[i] = i;
    writeServo(i, zeroPulse);
  }
  applyStartupSitPose();

  if (WIFI_SSID != nullptr && WIFI_SSID[0] != '\0') {
    WiFi.mode(WIFI_STA);
    WiFi.begin(WIFI_SSID, WIFI_PASS);
    uint32_t start = millis();
    while (WiFi.status() != WL_CONNECTED && (millis() - start) < 10000) {
      delay(200);
      Serial.print('.');
    }
    if (WiFi.status() == WL_CONNECTED) {
      tcpServer.begin();
      Serial.print("WIFI_OK,");
      Serial.print(WiFi.localIP());
      Serial.print(",PORT,");
      Serial.println(WIFI_PORT);
    } else {
      Serial.println("WIFI_ERR");
    }
  }

  sendReply("READY");
}

void handleLine(const String &line) {
  if (line == "ESTOP") {
    isMoving = false;
    emergencyStop();
    sendReply("ESTOP_OK");
    return;
  }

  if (line.startsWith("POSE,")) {
    float poseAngles[LOGICAL_JOINT_COUNT];
    uint16_t duration = defaultMotionDurationMs;
    if (!parsePoseCommand(line, poseAngles, duration)) {
      sendReply("POSE_ERR");
      return;
    }
    startPoseMotion(poseAngles, duration);
    sendReply(String("POSE_OK,") + String(duration));
    return;
  }

  if (line.startsWith("DUR,")) {
    int first = line.indexOf(',');
    if (first < 0) return;
    int value = line.substring(first + 1).toInt();
    defaultMotionDurationMs = (uint16_t)constrain(value, (int)MIN_MOTION_DURATION_MS, (int)MAX_MOTION_DURATION_MS);
    sendReply(String("DUR_OK,") + String(defaultMotionDurationMs));
    return;
  }

  if (line.startsWith("M,")) {
    int first = line.indexOf(',');
    int second = line.indexOf(',', first + 1);
    if (second < 0) return;
    uint8_t id = (uint8_t)line.substring(first + 1, second).toInt();
    uint16_t pulse = (uint16_t)line.substring(second + 1).toInt();
    writeMappedServo(id, pulse);
    uint8_t channel = mappedChannel(id);
    uint16_t constrainedPulse = constrain(pulse, SERVO_MIN, SERVO_MAX);
    String msg = String("M_OK,") + String(id) + "," + String(constrainedPulse) + ",CH,";
    if (channel < SERVO_COUNT) {
      msg += String(channel);
    } else {
      msg += "NA";
    }
    sendReply(msg);
    return;
  }

  if (line.startsWith("IDX,")) {
    int first = line.indexOf(',');
    int second = line.indexOf(',', first + 1);
    if (second < 0) return;
    uint8_t id = (uint8_t)line.substring(first + 1, second).toInt();
    uint8_t idx = (uint8_t)line.substring(second + 1).toInt();
    if (id >= SERVO_COUNT || idx >= SERVO_COUNT) return;
    motorMap[id] = idx;
    sendReply(String("IDX_OK,") + String(id) + "," + String(idx));
    return;
  }

  if (line.startsWith("SPD,")) {
    int first = line.indexOf(',');
    if (first < 0) return;
    int value = line.substring(first + 1).toInt();
    speedPercent = (uint8_t)constrain(value, 1, 100);
    defaultMotionDurationMs = (uint16_t)constrain((int)(DEFAULT_MOTION_DURATION_MS * (100.0f / speedPercent)), (int)MIN_MOTION_DURATION_MS, (int)MAX_MOTION_DURATION_MS);
    sendReply(String("SPD_OK,") + String(speedPercent));
    return;
  }
}

void consumeChars(Stream &stream, String &buffer) {
  while (stream.available() > 0) {
    char c = (char)stream.read();
    if (c == '\n' || c == '\r') {
      if (buffer.length() > 0) {
        handleLine(buffer);
        buffer = "";
      }
    } else {
      if (buffer.length() < 96) {
        buffer += c;
      } else {
        buffer = "";
      }
    }
  }
}

void pollWifiClient() {
  if (!tcpServer) return;

  if (!tcpClient || !tcpClient.connected()) {
    WiFiClient incoming = tcpServer.available();
    if (incoming) {
      if (tcpClient) {
        tcpClient.stop();
      }
      tcpClient = incoming;
      wifiLineBuffer = "";
      sendReply("WIFI_CLIENT_OK");
    }
  }

  if (tcpClient && tcpClient.connected()) {
    consumeChars(tcpClient, wifiLineBuffer);
  }
}

void loop() {
  consumeChars(Serial, lineBuffer);
  pollWifiClient();

  updateMotion();
}

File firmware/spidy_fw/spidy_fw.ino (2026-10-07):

// Spidy firmware v2: "dumb" servo driver. ALL calibration lives on the PC (config/calibration.json).
//
// Line protocol over USB serial (115200) or WiFi TCP port 5000 (host spidy.local):
//   P16,<16 ticks>   set all 16 PCA9685 channels (0 = channel off). Streamed ~50 Hz, no reply.
//   M,<ch>,<ticks>   set one physical channel                         -> M_OK,ch,ticks
//   OFF  (or ESTOP)  all channels off                                 -> OFF_OK
//   PING,<n>         latency check                                    -> PONG,<n>
//   IMU              read the MPU6050 (m/s^2, rad/s)                  -> IMU,ax,ay,az,gx,gy,gz | IMU_ERR
//   STATE            last ticks per channel                           -> STATE,<16 ticks>
//   BOOT,<16 ticks>  store the power-on pose in flash                 -> BOOT_OK
//   BOOT?            read it back                                     -> BOOT,<16 ticks> | BOOT,NONE
//   I2C?             bus scan + PCA write errors  -> I2C,devices=0x40 0x68,pca_begin=1,pca_write_errors=0
//   PCA?             PCA9685 registers read back   -> PCA,mode1=..,mode2=..,prescale=121,ch=<16 values|OFF|ERR>
//   HELLO            identify          -> SPIDY,fw=2,ip=<ip>,imu=<0|1>,boot=<reset reason>,up=<s>
//
// Failsafe: if a P16 stream stops for STALE_MS the servos HOLD their last pulse
// (the PCA9685 keeps outputting it on its own) and STALE is reported once.
// Power-on: the stored BOOT pose is applied. With no stored pose all outputs stay OFF.
//
// Ticks: PCA9685 at 50 Hz, 4096 ticks per 20 ms (1 tick = 4.88 us). Same
// oscillator settings as the old esp32_receiver, so old pulses mean the same thing.

#include <Wire.h>
#include <WiFi.h>
#include <ESPmDNS.h>
#include <Preferences.h>
#include <Adafruit_PWMServoDriver.h>
#include <Adafruit_MPU6050.h>
#include <Adafruit_Sensor.h>
#include <esp_system.h>
#include "secrets.h"   // WIFI_SSID / WIFI_PASS. Copy secrets.example.h -> secrets.h

static const uint8_t  CHANNELS   = 16;
static const uint16_t TICK_MIN   = 100;    // hard limits, same as the PC's HARD_MIN/HARD_MAX
static const uint16_t TICK_MAX   = 700;
static const uint32_t STALE_MS   = 300;
static const uint16_t TCP_PORT   = 5000;
static const size_t   MAX_LINE   = 200;

Adafruit_PWMServoDriver pwm(0x40);
Adafruit_MPU6050 mpu;
Preferences prefs;
WiFiServer server(TCP_PORT);
WiFiClient client;

uint16_t ticks[CHANNELS];      // what each channel outputs now, 0 = off
bool imuOk = false;
bool pcaOk = false;            // pwm.begin() found the PCA9685
uint32_t pcaWriteErrors = 0;   // setPWM() calls the chip did not acknowledge
bool streaming = false;
bool staleReported = false;
uint32_t lastP16 = 0;
String serialBuf, tcpBuf;

// Why did the ESP32 last start? Sent with READY/HELLO so the PC can tell a brownout
// (servo current spike pulled the supply down) from a crash or a normal power-on.
const char *resetReason() {
  switch (esp_reset_reason()) {
    case ESP_RST_POWERON:   return "poweron";
    case ESP_RST_BROWNOUT:  return "BROWNOUT";
    case ESP_RST_PANIC:     return "CRASH";
    case ESP_RST_INT_WDT:
    case ESP_RST_TASK_WDT:
    case ESP_RST_WDT:       return "WATCHDOG";
    case ESP_RST_SW:        return "software";
    case ESP_RST_EXT:       return "reset-pin";
    default:                return "other";
  }
}

// ------------------------------------------------------------------ output
void reply(const String &msg) {
  Serial.println(msg);
  if (client && client.connected()) client.println(msg);
}

void writeChannel(uint8_t ch, uint16_t t) {
  if (ch >= CHANNELS) return;
  if (t == 0) {                       // off: no pulse at all, servo goes limp
    if (pwm.setPWM(ch, 0, 4096)) pcaWriteErrors++;   // 4096 = the PCA9685 "full off" bit
    ticks[ch] = 0;
    return;
  }
  t = constrain(t, TICK_MIN, TICK_MAX);
  if (ticks[ch] == t) return;         // unchanged: skip the I2C write
  if (pwm.setPWM(ch, 0, t)) pcaWriteErrors++;      // non-zero return = I2C write failed
  ticks[ch] = t;
}

void allOff() {
  for (uint8_t ch = 0; ch < CHANNELS; ch++) writeChannel(ch, 0);
  streaming = false;
}

String ticksCsv(const uint16_t *v) {
  String s;
  for (uint8_t i = 0; i < CHANNELS; i++) {
    if (i) s += ',';
    s += String(v[i]);
  }
  return s;
}

// Parse "a,b,c,..." starting at index `from` into out[]. Returns how many numbers were read.
int parseInts(const String &line, int from, long *out, int maxN) {
  int n = 0;
  while (from <= (int)line.length() && n < maxN) {
    int comma = line.indexOf(',', from);
    if (comma < 0) comma = line.length();
    String tok = line.substring(from, comma);
    tok.trim();
    if (tok.length() == 0) break;
    out[n++] = tok.toInt();
    from = comma + 1;
  }
  return n;
}

// ------------------------------------------------------------------ boot pose (flash)
bool loadBoot(uint16_t *out) {
  prefs.begin("spidy", true);
  size_t n = prefs.getBytes("boot", out, sizeof(uint16_t) * CHANNELS);
  prefs.end();
  return n == sizeof(uint16_t) * CHANNELS;
}

void saveBoot(const uint16_t *v) {
  prefs.begin("spidy", false);
  prefs.putBytes("boot", v, sizeof(uint16_t) * CHANNELS);
  prefs.end();
}
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

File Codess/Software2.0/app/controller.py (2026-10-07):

"""RobotController: the one object between the GUI and the robot.

Every 20 ms (tick):
    target  <- one source: a running pose move/sequence, the gait, or the manual target
    target  <- clamped to each joint's safe range (calibration)
    q       <- SlewLimiter(target)          never faster than MAX_RATE deg/s
    sim     <- physics(q)  or  mirror(q)    depending on the view mode
    robot   <- P16 pulses from calibration  only when ARMED, connected and target is Real/Both

RAW mode (Motors tab "raw", calibration wizard): streaming stops and single
channels are driven directly with M,<ch>,<ticks>. The sim then shows what the
calibration THINKS those ticks mean.
"""
import os
import time

import numpy as np
from PySide6.QtCore import QObject, QTimer, Signal, Qt

from spidy import calibration as C
from spidy.calibration import Calibration, from_legacy_txt
from spidy.gait import CrawlGait
from spidy.imu import parse_imu
from spidy.kinematics import JOINT_NAMES
import threading

from spidy.link import Link, Pinger, resolve_host, discover
from spidy.motion import SlewLimiter, PoseMove, Sequence
from spidy.poses import PoseLibrary, from_legacy_poses
from spidy.sim import SimWorld

ROOT = os.path.dirname(os.path.dirname(os.path.abspath(__file__)))
CONFIG = os.path.join(ROOT, "config")
CAL_PATH = os.path.join(CONFIG, "calibration.json")
POSES_PATH = os.path.join(CONFIG, "poses.json")
LEGACY_DIR = os.path.join(ROOT, "..", "Software")     # the old tool's files, Codess/Software

DT = 0.02            # control tick, s (50 Hz, same as the PCA9685 frame rate)
MAX_RATE = 240.0     # deg/s, slew limit on every joint


def load_or_import():
    """config/*.json if present, else import the old tool's files once."""
    os.makedirs(CONFIG, exist_ok=True)
    msgs = []
    if os.path.exists(CAL_PATH):
        cal = Calibration.load(CAL_PATH)
    else:
        cal = from_legacy_txt(os.path.join(LEGACY_DIR, "spidy_calibration3.txt"))
        cal.save(CAL_PATH)
        msgs.append("calibration imported from spidy_calibration3.txt -> config/calibration.json")
    if os.path.exists(POSES_PATH):
        poses = PoseLibrary.load(POSES_PATH)
    else:
        poses = from_legacy_poses(os.path.join(LEGACY_DIR, "spidy_poses.txt"),
                                  os.path.join(LEGACY_DIR, "spidy_calibration3.txt"))
        poses.save(POSES_PATH)
        msgs.append("poses imported from spidy_poses.txt -> config/poses.json")
    return cal, poses, msgs


class RobotController(QObject):
    log = Signal(str)                 # human-readable log line
    rx = Signal(str)                  # raw line from the robot (main thread)
    link_changed = Signal(bool, str)
    link_verified = Signal(str)       # firmware answered HELLO: "fw=2,ip=...,imu=1"
    _discovered = Signal(object)
    _reconnected = Signal(object)     # (ip, ok, error) from the reconnect thread
    armed_changed = Signal(bool)
    mode_changed = Signal(str)
    imu_sample = Signal(object, object)   # accel, gyro (numpy)
    ticked = Signal()                 # after every control tick
    calibration_changed = Signal()

    _rx_from_thread = Signal(str)
    _status_from_thread = Signal(bool, str)

    def __init__(self):
        super().__init__()
        self.cal, self.poses, msgs = load_or_import()
        self.sim = SimWorld()
        self.gait = CrawlGait()
        self.slew = SlewLimiter(MAX_RATE)

        if "Standf" in self.poses.poses:          # the gait stands in YOUR tuned Standf
            self.gait.set_stance(self.poses.get("Standf"))
        self.target = self.gait.stance_deg.copy()  # manual target (deg)
        self.q = self.target.copy()              # what is actually commanded right now
        self.slew.reset(self.q)
        self.sim.reset(self.q)
        self.motion = None                       # PoseMove / Sequence / None
        self.motion_label = ""
        self.mode = "sim"                        # sim | real | both
        self.armed = False
        self.raw_mode = False
        self.raw_ticks = [0] * C.CHANNELS        # last raw tick per channel (raw mode)
        self.speed = 0.6                         # walk speed scale 0..1
        self._walk_after_move = None
        self._arm_wait = None
        self.imu_polling = False
        self.robot_state = None                  # last STATE reply (16 ticks)
        self.verified = False                    # Spidy firmware answered on this link
        self._hello_until = 0.0                  # keep asking HELLO until this time
        self._t_hello = 0.0
        self._warned_unarmed = 0.0
        self._tcp_ip = None                      # last Wi-Fi robot address (for auto-reconnect)
        self._user_disconnect = False
        self._reconnect_until = 0.0
        self._t_reconnect = 0.0
        self._reconnecting = False
        self._soft_start = None                  # time the soft start began (see _stream_pulses)
        self._boot_logged = False
        self._stream_state = None                # '' = streaming, else why not
        self.tx_frames = 0                       # P16 frames actually handed to the socket

        self.link = Link(on_line=self._rx_from_thread.emit, on_status=self._status_from_thread.emit)
        self._rx_from_thread.connect(self._on_line)
        self._discovered.connect(self._on_discovered)
        self._reconnected.connect(self._on_reconnected)
        self._status_from_thread.connect(self._on_status)
        self.pinger = Pinger()
        self._t_ping = self._t_imu = 0.0

        self.timer = QTimer(self)
        self.timer.setTimerType(Qt.PreciseTimer)   # Windows' default timer is ~16 ms coarse
        self.timer.timeout.connect(self.tick)
        self.timer.start(int(DT * 1000))
        self._t_last = time.monotonic()
        for m in msgs:
            QTimer.singleShot(0, lambda m=m: self.log.emit(m))

    # ================================================================ main loop
    def tick(self):
        # Real elapsed time, not the nominal 20 ms: if the GUI delays a tick, the sim,
        # the gait and pose moves still run in real time. Capped so a long stall
        # (window drag, breakpoint) doesn't produce one giant step.
        now = time.monotonic()
        dt = min(now - self._t_last, 0.1)
        self._t_last = now
        if self.motion is not None:
            tgt = self.motion.update(dt)
            if self.motion.done:
                self.target = np.array(tgt)
                self.motion = None
                self.motion_label = ""
                if self._walk_after_move is not None:
                    self.gait.set_command(*self._walk_after_move)
                    self._walk_after_move = None
        elif self.gait.walking or np.abs(self.gait.cmd).max() > 0:
            tgt = self.gait.update(dt)
            if not self.gait.walking:
                self.target = np.array(tgt)
        else:
            tgt = self.target
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

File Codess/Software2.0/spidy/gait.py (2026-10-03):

"""Crawl (wave gait) driven by a live command. The maths is sim_walk/step4 + step5.

    gait = CrawlGait()
    gait.set_command(forward=1.0, turn=0.0)     # -1..1 each, change any time
    q_deg = gait.update(dt)                     # call every tick -> 12 joint angles (deg)

When the command goes to zero the gait fades out over RAMP seconds and ends in
the stance pose, so "stop" never leaves a leg in the air.
"""
from dataclasses import dataclass

import numpy as np

from .kinematics import LEGS, leg_fk, feet_to_angles, rot_z, standf_deg


def smooth(s):
    s = np.clip(s, 0.0, 1.0)
    return 0.5 - 0.5 * np.cos(np.pi * s)


@dataclass
class GaitParams:
    cycle: float = 2.4          # s for all four legs to step once
    swing: float = 0.15         # fraction of the cycle a foot is in the air
    lift: float = 0.025         # m, swing height
    max_step: float = 0.06      # m of body travel per stance at forward = 1
    max_turn: float = 15.0      # deg of body turn per cycle at turn = 1
    sway_x: float = 0.02        # m, fore-aft lean
    sway_y: float = 0.02        # m, sideways lean
    sway_sharp: float = 2.0     # how square the side sway is (see step4)
    tuck: float = 0.015         # m, feet pulled in from the stance pose while walking
    ramp: float = 2.4           # s to fade the gait in / out
    cmd_smooth: float = 0.4     # s, time constant for command changes


PHASE = {"br": 0.0, "fr": 0.25, "bl": 0.5, "fl": 0.75}


class CrawlGait:
    def __init__(self, stance_deg=None, params=None):
        self.p = params or GaitParams()
        self.set_stance(standf_deg() if stance_deg is None else stance_deg)
        self.phase = 0.0          # 0..1 through the cycle
        self.amount = 0.0         # 0 = standing, 1 = full gait
        self.cmd = np.zeros(2)    # target (forward, turn), -1..1
        self.cmd_s = np.zeros(2)  # smoothed command actually used

    def set_stance(self, stance_deg):
        """Stance pose (12 joint degrees) -> foot spots the gait walks around."""
        self.stance_deg = np.asarray(stance_deg, float)
        q = np.radians(self.stance_deg)
        self.stance_feet = {leg: leg_fk(leg, q[3 * i: 3 * i + 3]) for i, leg in enumerate(LEGS)}

    def set_command(self, forward, turn):
        self.cmd = np.clip([forward, turn], -1, 1)

    @property
    def walking(self):
        return self.amount > 0

    def update(self, dt):
        p = self.p
        k = min(1.0, dt / p.cmd_smooth)
        self.cmd_s += (self.cmd - self.cmd_s) * k

        want = np.abs(self.cmd).max() > 0.02
        self.amount = float(np.clip(self.amount + (dt if want else -dt) / p.ramp, 0, 1))
        if self.amount == 0:
            self.phase = 0.0
            self.cmd_s[:] = 0
            return self.stance_deg.copy()
        self.phase = (self.phase + dt / p.cycle) % 1.0
        return np.degrees(feet_to_angles(self.feet(self.phase, self.amount, *self.cmd_s)))

    # ---- the gait itself: pure function of (phase, amount, command)
    def feet(self, phi, r, forward, turn):
        p = self.p
        step = r * forward * p.max_step
        turn_st = np.radians(r * turn * p.max_turn) * (1 - p.swing)   # body turn per stance
        sway = r * np.array([p.sway_x * np.cos(4 * np.pi * (phi - 0.1)),
                             p.sway_y * np.clip(p.sway_sharp * np.sin(2 * np.pi * (phi + 0.05)), -1, 1)])
        out = {}
        for leg, (sx, sy) in LEGS.items():
            spot = self.stance_feet[leg] + [0, -sy * r * p.tuck, 0]

            def on_ground(u):          # u: 0 just landed .. 1 lifting
                q = rot_z(turn_st * (0.5 - u)) @ spot
                return q + [step * (0.5 - u), 0, 0]

            lp = (phi - PHASE[leg]) % 1.0
            if lp < p.swing:
                s = lp / p.swing
                a, b = on_ground(1.0), on_ground(0.0)
                f = a + (b - a) * smooth(s)
                f[2] += r * p.lift * np.sin(np.pi * s) ** 2
            else:
                f = on_ground((lp - p.swing) / (1 - p.swing))
            out[leg] = f - [sway[0], sway[1], 0]
        return out

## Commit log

2026-10-02 Initial commit: Spidy Bot quadruped
    Firmware and calibration tools (merged from the old MAKDA repo),
    printable parts, Fusion-exported STLs, URDF/xacro description and
    MuJoCo model with check scripts.
    [2legs.3mf, BUCK.stl, Battery.stl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]
2026-10-02 feat: add spidy robot URDF description, MuJoCo model, and generation scripts
    [spidy.urdf, spidy.urdf.xacro, spidy.xml]
2026-10-02 feat: add spidy robot model configuration and simulation files
    [spidy.urdf, spidy.xml, spidy_generated.xacro]
2026-10-02 feat: add step-by-step quadruped walking simulation framework and motion scripts
2026-10-03 Add IMU and kinematics modules, implement motion helpers, and enhance pose management
